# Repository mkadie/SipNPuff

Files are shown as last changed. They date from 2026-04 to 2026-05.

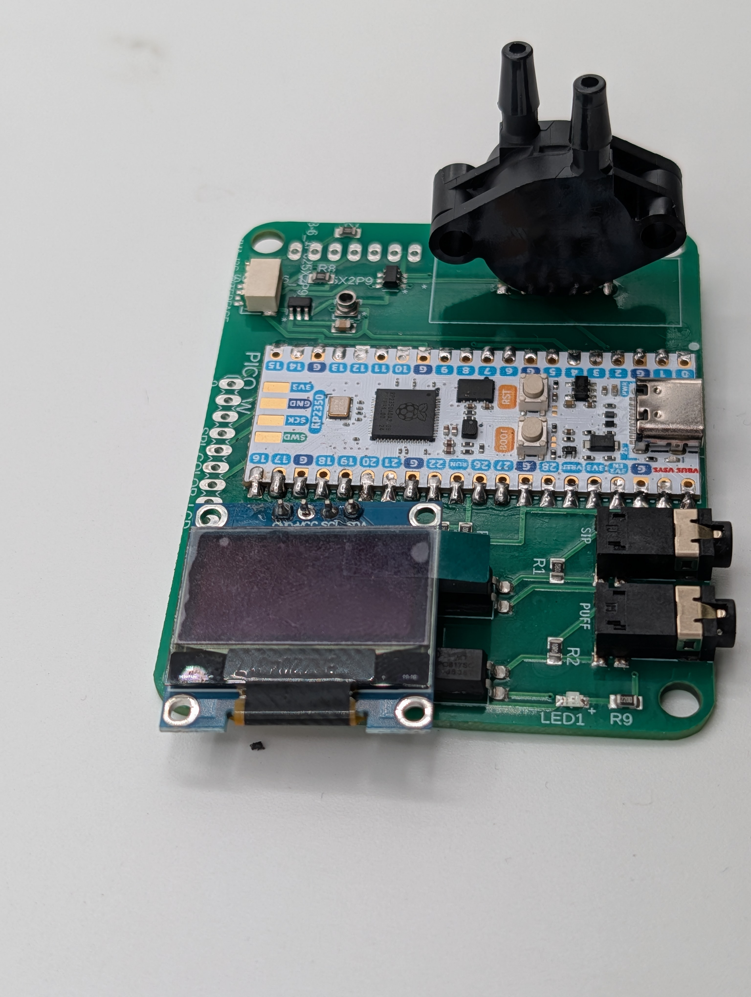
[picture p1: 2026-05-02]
photos/PXL_20260430_184801016.jpg

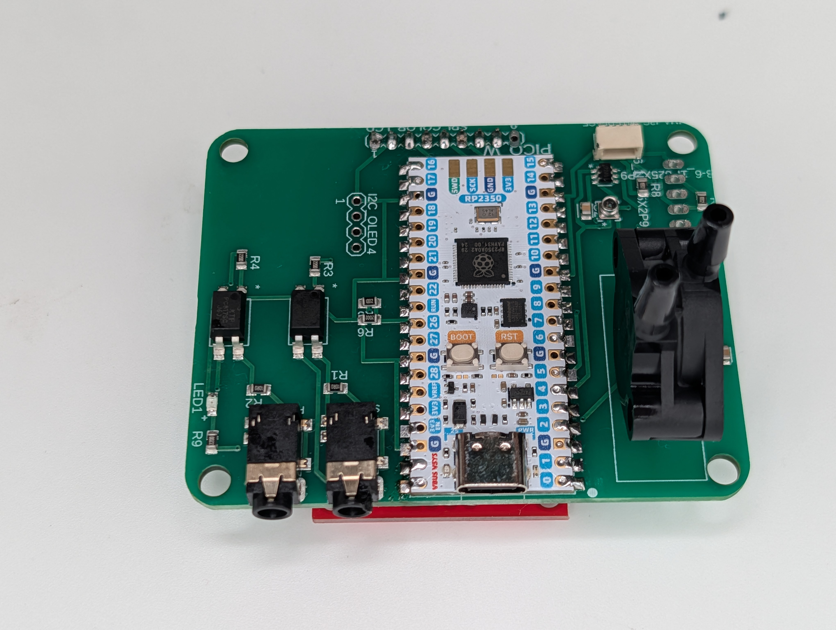
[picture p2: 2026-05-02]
photos/PXL_20260430_184728154.jpg

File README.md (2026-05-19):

# Sip and Puff Rubber Chicken Edition

## Project Overview

This project implements a functional sip and puff switch interface that serves as both a demonstration system (using rubber chickens) and a working, low-cost ($25-50) sip and puff device for accessibility applications. The core functionality focuses on creating a reliable, accessible interface while using the rubber chicken concept as an engaging demonstration tool for normally abled users.

---

## ⭐ Primary Claim to Fame: One Build, Many Purposes — Text File Configuration

> **The defining characteristic of this project is flexibility.**

Most open-source sip and puff devices are purpose-built for a single output: a USB mouse, a keyboard emulator, or a specific AT protocol. Changing what the device *does* means reflashing firmware or editing code. This project takes a different approach: **a single hardware build and a single firmware image that can be reconfigured for completely different tasks by editing a plain text configuration file** — no compiler, no IDE, no programmer required.

A clinician, caregiver, or technically capable user can open the config file (accessible as a USB drive when the device is plugged in) and change:
- What a sip or puff event maps to (keypress, mouse button, joystick axis, HID consumer control, serial command, etc.)
- Sensitivity thresholds for sip and puff, independently
- Operating mode (USB HID mouse, USB HID keyboard, XAC gamepad output, serial AT command relay, etc.)
- Head-tracking parameters (dead zone, speed curve, re-centre trigger gesture)
- Display content and feedback behaviour

The same physical device can serve as:
- A USB mouse (head tracking + sip/puff clicks)
- A two-switch keyboard input (sip = one key, puff = another)
- An Xbox Adaptive Controller input (via the onboard TRRS jacks)
- A demonstration interface (rubber chicken mode for Maker faires)
- A research data collection tool (with optional microSD logging)

No other project in the open-source sip and puff space offers this level of reconfigurability without touching firmware. This is intentional and is the core design goal that drives decisions about display hardware, the EXTERNAL_IO connector, STEMMA QT expansion, and the overall software architecture.

---

## Project Stage

Early, rapid development for prototype by Maker event, which one ... hopefully the next one :)

> **Firmware reference:** see [`FIRMWARE_NOTES.md`](./FIRMWARE_NOTES.md)
> for the current state of the CircuitPython firmware — pressure-sensor
> fusion, event-classifier rules, the on-screen HUD layout, the repeat-rate
> map, IMU pointing, and the full config-key reference. That's the document
> to read before touching `source/breath_classifier.py`,
> `source/sip_puff_device.py`, or any `config.txt` on a deployed device.

## Core Mission

### Primary Focus: Flexibility Through Text File Configuration
The defining goal is a single hardware and software build that can be reconfigured for a wide range of tasks by editing a plain text config file — no reflashing, no coding skills required. The same device adapts to the user, rather than requiring the user to adapt to a fixed device behavior.

### Secondary Focus: Functional Accessibility Interface
The main objective is to develop a robust, affordable sip and puff switch system that can be used for:
- Assistive technology for individuals with motor disabilities
- Accessibility solutions for communication devices
- Research in human-computer interaction
- Educational demonstrations in accessibility technology

### Tertiary Focus: Demonstration and Engagement
The rubber chicken concept serves as an engaging demonstration tool for:
- Maker faires and community events
- Educational outreach programs
- Public demonstrations of accessibility technology
- Engaging users in the concept of assistive interfaces

## Hardware Design

### Primary Components

#### Sensors

> **PCB Strategy:** Initial PCBs support both sensor footprints simultaneously. After real-world testing, separate PCB variants (SMD-only and through-hole) will be produced.

##### Default Sensor: LPS28DFWTR (SMD — I²C digital)
- **Part:** STMicroelectronics LPS28DFWTR
- **Package:** CCLGA-7L, 2.8 × 2.8 × 1.95 mm — SMD only, requires reflow or hot-air soldering
- **Why it's default:** Water-resistant package (potting gel, rated 10 ATM), 24-bit resolution, ultra-low noise (0.32 Pa), factory-calibrated, I²C interface, embedded FIFO, interrupt output, and 1.7 µA idle current
- **Interface:** I²C (up to 400 kHz fast mode; 1 MHz fast mode+) — connects directly to Pico W I²C bus
- **I²C address:** 0x5C (SA0 pin → GND) or 0x5D (SA0 pin → VDD) — selectable via PCB solder bridge
- **Pressure range:** Mode 1: 260–1260 hPa (optimised for sip/puff); Mode 2: 260–4060 hPa
- **Pressure noise:** 0.32 Pa RMS (Mode 1) — more than sufficient for breath detection
- **Accuracy:** ±0.5 hPa absolute, ±0.015 hPa relative
- **ODR:** 1–200 Hz (software configurable)
- **Supply voltage:** 1.7 to 3.6 V (3.3V from Pico W is within spec)
- **Interrupt:** INT_DRDY pin — data-ready interrupt for efficient polling
- **Datasheet:** DS13317 Rev 1, December 2021 (ST Microelectronics)
- **Sensor Placement:** Positioned in breath path between mouthpiece filter and PCB; water-resistant package tolerates condensation exposure

##### Alternative Sensor: MPX5010DP (Through-Hole — Analog output)
- **Part:** NXP/Freescale MPX5010DP
- **Package:** Through-hole SIP-6 — can be hand-soldered without SMD equipment
- **Why it's an alternative:** Easier to hand-solder for early prototypes and events; no SMD tools required
- **Interface:** **Analog voltage output** (0.2V–4.7V at 5V supply) — connects to a Pico ADC pin, **NOT I²C**
- **Pressure range:** 0–10 kPa differential
- **Supply voltage:** 2.7–5.5V (note: at 3.3V supply the output range scales; verify output headroom in firmware)
- **Accuracy:** ±1.5% FS
- **Power consumption:** ~6 mA typical (significantly higher than LPS28DFWTR)
- **Sensor Placement:** Same breath-path position; analog output wire routes to GPIO 26 (ADC0) on Pico W

#### Microcontroller
- **Raspberry Pi RP2040**: Chosen for its cost-effectiveness ($4), dual-core ARM Cortex-M0+ processor, and sufficient processing power for signal conditioning
- **Alternative Options**: 
  - ESP32 for WiFi connectivity
  - Arduino Nano for simpler implementations
  - STM32 for higher performance applications
- **Processing Requirements**: Signal filtering, input classification, and output protocol handling

#### Mechanical Interface
- **Primary Sip/Puff Mechanism**: 
  - Standard straw or tube for suction input
  - Blow tube for pressure input
  - Ergonomic design for comfortable use
- **Alternative Interfaces**: 
  - Custom 3D printed mouthpieces
  - Commercial sip/puff devices
  - Modular interface system for different user needs
- **Enclosure Design**: 
  - Durable, medical-grade materials
  - Easy-to-clean surfaces
  - Ergonomic housing for various user groups
- **Interface Options**: 
  - Standard straw configuration
  - Bellows system for precise suction detection
  - Custom mouthpiece designs

#### Optional Display Connectors

> Both connectors are unpopulated PCB footprints — built-in hardware support with no board redesign needed to add displays later.

##### J1 — I²C OLED Display (1", 128×64)
- **Connector**: 4-pin 2.54 mm Dupont header on PCB
- **Display type**: 1" 128×64 OLED, SSD1306 controller (or compatible)
- **Interface**: I²C — shares existing GPIO 4 (SDA) / GPIO 5 (SCL) bus with the LPS28DFWTR sensor
- **I²C address**: 0x3C (default) or 0x3D — no conflict with LPS28DFWTR at 0x5C/0x5D
- **Supply**: 3.3V
- **Pin order (1→4)**: GND → VCC → SCL → SDA
- **Use case**: Status readout, sip/puff feedback, pressure level bar graph

##### J2 — SPI Color LCD Display (2"–4")
- **Connector**: 9-pin 2.54 mm Dupont header on PCB
- **Display type**: 2"–4" color TFT LCD, ST7789 or ILI9341 controller (or compatible)
- **Interface**: SPI1 hardware peripheral on dedicated non-analog GPIO pins
- **GPIO assignments**:
  - GPIO 10 — SCK (SPI1 clock)
  - GPIO 11 — MOSI / SDI (SPI1 TX)
  - GPIO 12 — MISO / SDO (SPI1 RX, optional)
  - GPIO 13 — CS (chip select, active low)
  - GPIO 14 — DC/RS (high = data, low = command)
  - GPIO 15 — RESET (active low)
  - GPIO 16 — LED (backlight PWM; solder bridge for always-on 3.3V)
- **Pin order (1→9)**: VCC → GND → CS → RESET → DC/RS → MOSI → SCK → LED → MISO
- **Supply**: 3.3V
- **Use case**: Full-color rubber chicken game interface, animated demo display

#### Circuit Protection

> **A commonly overlooked step in open-source hardware projects, including many assistive technology designs.** External-facing I/O lines that connect to the real world — connectors, encoder inputs, expansion ports — are exposed to ESD events and electrical transients. Protecting the microcontroller's GPIO pins from these events is straightforward and inexpensive; skipping it is a common cause of latent damage in both hobby and clinical builds.

- **IC:** SP724AHTG — low-capacitance TVS (transient voltage suppressor) diode array, STMicroelectronics
- **Coverage:** All external-facing I/O lines **not** already protected by opto-isolation:
  - EXTERNAL_IO connector: BUTTON (GPIO 20), ROT_A (GPIO 18), ROT_B (GPIO 19), SDA (GPIO 4), SCL (GPIO 5)
  - STEMMA QT expansion port (SDA, SCL)
  - Display connectors J1 and J2 signal lines as applicable
- **Not needed on:** GPIO 0 (SIP_ENABLE) and GPIO 1 (PUF_ENABLE) — these are already isolated by PC817SC optocouplers before reaching the TRRS jacks
- **Why SP724AHTG:** Low capacitance preserves signal integrity on I²C and SPI lines; small package; single IC can protect multiple lines simultaneously; ~$0.30–0.50 per IC in single-unit quantities

#### Power Supply
- **Battery Option**: PCB designed to accommodate battery but not populated (user-selectable)
- **Optional LDO Power Supply**: For chair-based installations at events
- **Power Management**: 
  - Standalone operation with optional power expansion
  - Low power consumption design for battery operation
  - USB charging capability for convenience
- **Power Requirements**: 
  - Standby: <10mA
  - Active: <50mA
  - Battery life: >20 hours continuous operation

### Cost Analysis

| Component | Cost (single unit) | Notes |
|---|---|---|
| Pressure sensor — LPS28DFWTR | ~$4–6 | **Primary / default.** STMicroelectronics CCLGA-7L SMD; I²C, 24-bit, 0.32 Pa noise, water-resistant potting gel. Requires reflow or hot-air soldering. |
| Microcontroller | ~$4 | Raspberry Pi Pico W (RP2040 + CYW43439) |
| XAC output circuit | ~$2–3 | 2× PC817SC optocouplers + 2× TRRS jacks |
| Circuit protection | ~$1–2 | SP724AHTG TVS array ICs × 2–3 units; protects all I/O lines not covered by opto-isolators |
| Mechanical components | ~$5–10 | Tube, mouthpiece, connectors |
| Enclosure materials | ~$5–10 | 3D-printed or off-the-shelf housing |
| Miscellaneous | ~$5–10 | Resistors, caps, PCB, hardware |
| **Base build total** | **~$21–45** | Functional sip/puff device with XAC output and ESD protection |
| **Optional — MPX5010DP sensor** | **+~$3–5** | Through-hole analog alternative to the LPS28DFWTR; hand-solderable, no SMD tools required. *Depending on performance testing of the LPS28DFWTR vs MPX5010DP, this may remain a supported alternative or be retired from the design.* PCB includes footprint for both — only one is populated. |
| **Optional — BNO055 IMU** | **+~$30–35** | Bosch BNO055 on STEMMA QT breakout (e.g. Adafruit #4646); adds head-tracking (Mode A) and/or tongue-joystick cursor control (Mode B). Post-Maker-Faire upgrade — not required for core sip/puff functionality. Sensor alone costs more than the rest of the BOM combined at single-unit prices. |
| **Optional — display(s)** | **+~$5–15** | J1: 1" SSD1306 OLED ~$3–5; J2: 2–4" color LCD ~$8–15; PCB connectors already present |
| **Optional — hygiene filters** | **~$0.50–2 each** | Recurring consumable; see Section 10.1 of reference doc for filter options |
| **Full build with IMU + display** | **~$56–95** | Still well below comparable commercial AT devices ($175–$325+) |
| **Future / Medical-grade — redundant hardware** | **+~$15–30 est.** | For a medically certified build: a second LPS28DFWTR pressure sensor (cross-checks primary; flags discrepancy as fault condition) plus a second or dedicated safety CPU (hardware watchdog / supervisory MCU to monitor the primary RP2040 and force a safe state on failure). Required for IEC 62304 / FDA Class II pathway. Significant increase in PCB complexity and firmware scope. Not planned for current prototype — noted here as the architectural direction a certified variant would take. The lead designer has prior involvement in the design and manufacture of an FDA-regulated medical device (a lithium battery system for power wheelchairs, developed in conjunction with an established powerchair manufacturer), making this a realistic rather than purely aspirational future direction. See Section 10.7 of the reference doc for full detail. |

- **Manufacturing Considerations**: 
  - Scalable production design
  - Component sourcing for cost optimization
  - Quality control procedures

## Software Architecture

### Core Functionality

The system operates as a reliable, functional sip and puff interface with the following core features:

1. **Pressure Sensing**: Continuous monitoring of pressure sensor data with filtering — I²C polling (LPS28DFWTR default) or ADC sampling (MPX5010DP alternative)
2. **Input Classification**: Distinguishing between sip and puff actions with threshold detection
3. **Signal Processing**: Debouncing and smoothing of pressure readings
4. **Command Generation**: Converting pressure inputs into actionable commands
5. **Output Protocol**: Providing standardized outputs for various applications

### Input/Output Processing

#### Input Detection
- **Suction Detection**: Threshold detection for negative pressure (sip)
- **Blow Detection**: Threshold detection for positive pressure (puff)
- **Hold Detection**: Continuous pressure monitoring for extended commands
- **Debouncing**: Filtering for false triggers and noise reduction

#### Output Protocols
- **Digital Outputs**: 
  - Binary signals for on/off commands
  - Multi-level outputs for different command types
  - Serial communication for complex data transfer
- **Analog Outputs**: 
  - Voltage level representation of pressure
  - Proportional response for advanced applications
- **Communication Protocols**: 
  - I2C for LPS28DFWTR sensor communication (default); ADC for MPX5010DP (alternative)
  - UART for serial data transfer
  - USB for PC connectivity

### Command Structure
- **Basic Commands**: 
  - Sip (negative pressure)
  - Puff (positive pressure)
  - Hold (extended pressure)
- **Advanced Commands**: 
  - Double tap
  - Long press
  - Pattern recognition
- **Customizable Mapping**: 
  - User-defined command associations
  - Application-specific command sets

## Technical Specifications

### Electrical Specifications
- **Supply Voltage**: 3.3V or 5V (user selectable)
- **Current Consumption**: <50mA (standby), <100mA (active)
- **Operating Temperature**: -20°C to +70°C
- **Humidity Range**: 5% to 95% RH (non-condensing)
- **Input Impedance**: High impedance for sensor compatibility
- **Output Impedance**: Low impedance for reliable signal transmission

### Mechanical Specifications
- **Dimensions**: 150mm × 100mm × 50mm (approximate)
- **Weight**: <200g (excluding power source)
- **Input Force Range**: -500Pa to +500Pa
- **Response Time**: <100ms for pressure changes
- **Interface Materials**: Medical-grade, non-toxic materials
- **Durability**: >100,000 cycles of operation

### Performance Metrics
- **Accuracy**: ±2% for pressure measurements
- **Repeatability**: ±1% across multiple readings
- **Detection Threshold**: 50Pa for both suction and blowing
- **Operating Life**: >100,000 cycles
- **Reliability**: 99.5% uptime under normal conditions
- **Noise Resistance**: >60dB signal-to-noise ratio

## Accessibility Applications

### User Groups
- **Motor Disabled Individuals**: 
  - Spinal cord injury patients
  - Cerebral palsy users
  - ALS patients
  - Stroke recovery patients
- **Communication Needs**: 
  - Augmentative and alternative communication (AAC)
  - Voice output communication aids
  - Environmental control systems
- **Research Applications**: 
  - Motor function assessment
  - Rehabilitation technology
  - User interface studies

### Integration Capabilities
- **Communication Devices**: 
  - Text-to-speech systems
  - Voice synthesis units
  - Communication boards
- **Environmental Control**: 
  - Home automation systems
  - Lighting controls
  - Temperature regulation
- **Assistive Technology**: 
  - Wheelchair controls
  - Computer interface systems
  - Mobile device control

## Demonstration System (Rubber Chicken Concept)

### Purpose
- **Engagement Tool**: Make accessibility technology approachable and fun
- **Educational Aid**: Demonstrate principles of sip and puff technology
- **Community Outreach**: Attract attention to accessibility needs
- **Public Awareness**: Showcase assistive technology capabilities

### Demonstration Features
- **Rubber Chicken Interface**: 
  - Visual representation of the technology
  - Engaging user experience
  - Easy to understand concept
- **Interactive Gameplay**: 
  - Educational quiz system
  - Game-based learning
  - User engagement metrics
- **Public Display**: 
  - Maker faire setup
  - Educational booth
  - Community demonstration

### Technical Integration
- **Dual Functionality**: 
  - Real sip/puff system for actual use
  - Demonstration system for public engagement
- **Switching Mechanism**: 
  - User-selectable modes
  - Automatic mode detection
  - Context-aware operation

## Open Source Philosophy

### Documentation
- **Hardware**: Complete schematics, PCB layouts, BOM
- **Software**: Full source code with detailed comments
- **Assembly**: Step-by-step instructions
- **Calibration**: Testing and validation procedures
- **Applications**: Usage examples and integration guides

### Community Engagement
- **GitHub Repository**: Collaborative development environment
- **Issue Tracking**: Feature requests and bug reporting
- **Contribution Guidelines**: Clear development standards
- **Version Control**: Stable releases and development branches
- **Integration Tools**: Compatibility with maker ecosystem

## Research and Development Applications

### Academic Potential
- **Human-Computer Interaction**: 
  - Accessible interface design
  - User experience studies
  - Motor disability research
- **Assistive Technology**: 
  - Device development
  - User testing protocols
  - Technology evaluation
- **Engineering Education**: 
  - Hands-on learning projects
  - Design methodology
  - Prototyping techniques

### Publication Goals
- **IEEE Venues**: 
  - Accessibility technology papers
  - Human-computer interaction research
  - Assistive device development
- **Conference Presentations**: 
  - Maker faire demonstrations
  - Educational outreach
  - Research findings
- **Academic Papers**: 
  - Technical specifications
  - Performance analysis
  - User study results

## Scalability and Future Development

### Modular Design
- **Interface Expansion**: 
  - Different mechanical configurations
  - Customizable user interfaces
  - Modular component system
- **Protocol Support**: 
  - Multiple output standards
  - Integration with existing systems
  - Future-proof architecture
- **Upgrade Path**: 
  - Hardware improvements
  - Software enhancements
  - Feature additions

### Market Applications
- **Educational Institutions**: 
  - STEM learning tools
  - Engineering design projects
  - Accessibility education
- **Healthcare Providers**: 
  - Assistive technology solutions
  - Rehabilitation equipment
  - Clinical research tools
- **Research Labs**: 
  - Human-computer interaction studies
  - Device development
  - User interface research

## Conclusion

The Sip and Puff Rubber Chicken Edition represents a dual-purpose system that successfully balances accessibility functionality with community engagement. While the core focus remains on creating a reliable, affordable sip and puff interface for individuals with motor disabilities, the rubber chicken demonstration serves as an effective tool for public education and community outreach.

This approach ensures that the technology serves its primary purpose of supporting accessibility needs while also generating interest and understanding in the broader community. The system's modular design, open source nature, and focus on affordability position it well for both immediate practical applications and long-term research and development opportunities.

The project demonstrates how maker culture can contribute meaningfully to accessibility technology, creating solutions that are not only functional but also engaging and educational. By maintaining focus on the core sip and puff functionality while using the rubber chicken concept for demonstration, this system successfully bridges the gap between serious assistive technology and community engagement.

## Future

Taking inspiration from other sip and puff open source projects we will attempt to integrate mouse functionality after Maker Faire as time and schedule permit. The mouse feature is a software extension and should be comparatively easy.

### Head-Tracking via IMU (Phase 2 — Post-Maker-Faire)

The longer-term plan is to add **head-movement-based cursor control** using an IMU sensor, combining it with sip/puff for mouse clicks. This approach was validated in a peer-reviewed 2025 study ([S1] in the Reference doc) and is well-suited to users with high-level spinal cord injury or other conditions where oral motor control is limited.

**Selected sensor: Bosch BNO055** (~$30–35 on a STEMMA QT breakout)

The BNO055 was chosen over cheaper 6-DOF alternatives (MPU-6050, BMI270, LSM6DSOX) because it includes an on-board sensor fusion processor that outputs clean Euler angles and quaternions directly — no Kalman or Madgwick filter to implement. Its built-in magnetometer (9 DOF) also eliminates the yaw drift problem that affects 6-axis-only sensors during prolonged use, which is a real usability burden for a head mouse used over hours. The cost premium (~$25 over a basic IMU) is justified in context — it is a one-time addition, comparable in scale to a few rounds of replacement hygiene filters.

**Two mounting modes — same hardware, different placement:**

**Mode A — Head Strap / Glasses Mount:** The BNO055 is clipped to a glasses frame, forehead strap, or ear clip. Head nods and tilts move the cursor. Best for users with good head mobility. I²C wires run from the STEMMA QT port along the tube to the sensor on the head.

**Mode B — Tongue Joystick via Straw Attachment:** A small 3D-printed collar clips the BNO055 to the sip/puff tube near the mouthpiece. The user deflects the straw with their tongue — left, right, up, down — and the BNO055 detects the angular change of the tube. The straw becomes the joystick lever. Best for users with good tongue or lip control but limited head movement. Same hardware as Mode A, just repositioned.

With proper configuration the required activation force can be significantly reduced. The collar's position along the tube acts as a lever — moving it further from the tip lengthens the lever arm so a lighter tongue push produces a larger angular signal. Tube material flexibility also plays a role. On the software side, the sensitivity and dead zone settings in the config file can be tuned so that very small movements register as valid input without making the cursor jittery at rest. This makes Mode B viable for users with very limited tongue or lip strength, and gives clinicians a way to adjust force requirements without any hardware changes.

Switching between modes is a config file change (sensitivity, dead zone, and axis orientation parameters) — no reflashing required. This is a direct expression of the project's core flexibility goal.

**Hardware readiness:** No PCB changes are needed. The STEMMA QT expansion port (GPIO 4/5 I²C bus) is already present on the board for exactly this purpose. The BNO055's I²C address (0x28 or 0x29) does not conflict with any other device on the shared bus.

A three-way hybrid — head tracking, tongue joystick, and Hall-effect mouthpiece stick as selectable modes on the same hardware — is a longer-term stretch goal. No existing reviewed open-source project offers even two of these three options.

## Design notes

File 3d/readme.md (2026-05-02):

# 3D Models

Mechanical models for the T-Rex Sip-N-Puff HID enclosure and assembly.

## Contents

| File | Format | Description |
|---|---|---|
| `SipNPuff.step` | STEP (AP214) | First article prototype assembly — full 3D model of the electronics and enclosure concept |

## Importing the STEP File

The STEP file can be opened in any major CAD package:

- **Fusion 360** — File → Open → select `.step`
- **FreeCAD** — File → Import → select `.step`
- **SolidWorks** — File → Open → select `.step`
- **KiCad 3D Viewer** — for PCB enclosure fit checks

If you downloaded the compressed `.step.gz` version, decompress it first:

```bash
gunzip SipNPuff.step.gz
```

## Notes

- This model represents the first article prototype. Enclosure design will evolve as the project moves from breadboard to production form factor.
- See the `photos/` directory for build photos of this prototype.
- Electronics BOM, schematic, and firmware are in the project root.

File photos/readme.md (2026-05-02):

# Prototype Photos

First article prototype of the T-Rex Sip-N-Puff HID electronics assembly.

These photos document the initial build of the Raspberry Pi Pico-based sip and puff human interface device, including the MPX5010DP pressure sensor, PC817 optocoupler outputs for the Xbox Adaptive Controller, and optional I2C display modules.

## Contents

| File | Description |
|---|---|
| PCB front view | Top side of the assembled board showing the Pico, pressure sensor, and supporting components |
| PCB back/rotated | Reverse angle showing board layout |
| PCB with TFT display | Assembly with TFT display module attached via I2C |
| PCB with OLED and tubing | Assembly with OLED display and sip/puff tubing connected to the MPX5010DP |
| PCB underside | Solder joint quality on the bottom of the board |
| Full assembly | Complete build with sip tube mounted to the board |

## Notes

- This is a first article prototype — form factor and layout are subject to change as the enclosure design matures.
- See the `3d/` directory for the initial mechanical model.
- See the project root for full BOM, schematic, and firmware.

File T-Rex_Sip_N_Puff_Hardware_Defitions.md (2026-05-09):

Got it—less talk, more traces. Since you're using the **Raspberry Pi Pico** layout and want to keep your **SPI interfaces** wide open while maintaining a specific pin order for the encoder, we’ll move the logic to the "bottom" end of the Pico’s GPIO bank.

This configuration uses **GP26** (the lowest ADC) for the chicken-bellows sensor and groups your encoder outputs together starting at **GP18**, leaving **GP0–GP7 (SPI0)** and **GP8–GP11 (SPI1)** completely untouched for your other hardware needs.

### 1. Hardware Mapping & Schematic Logic

| Pico Pin | Label | Function | Connection Note |
| :--- | :--- | :--- | :--- |
| **VBUS (Pin 40)** | 5V_RAIL | Power for MPX5010DP | [cite_start]Use the 5V USB line to power the sensor[cite: 9]. |
| **GND (Pin 38)** | GND | Common Ground | [cite_start]Tie all sensor, opto, and Pico grounds here[cite: 22]. |
| **GP26 (Pin 31)** | ADC0 | Pressure Input | [cite_start]Lowest ADC; requires a voltage divider (see below)[cite: 15, 16]. |
| **GP16 (Pin 21)** | XAC_PULSE | Opto 1 Control | [cite_start]Drives the "Puff" signal to the Xbox Controller[cite: 13, 21]. |
| **GP17 (Pin 22)** | XAC_SELECT | Opto 2 Control | [cite_start]Drives the "Double Puff" signal to the XAC[cite: 13, 21]. |
| **GP18 (Pin 24)** | ENC_A | Encoder Phase A | First part of the consecutive encoder block. |
| **GP19 (Pin 25)** | ENC_B | Encoder Phase B | Middle of the consecutive encoder block. |
| **GP20 (Pin 26)** | ENC_BTN | Encoder Button | End of the consecutive block; no "middle" button. |

---

### 2. Critical Wiring Sub-Circuits

#### **The Voltage Divider (Pressure Sensor)**
[cite_start]The MPX5010DP outputs up to **4.7V**, which will fry your Pico's ADC if connected directly[cite: 14, 15].
* [cite_start]**Sensor Output Pin** $\rightarrow$ $10k\Omega$ Resistor $\rightarrow$ **Pico GP26 (ADC0)**[cite: 12, 16].
* [cite_start]**Pico GP26 (ADC0)** $\rightarrow$ $20k\Omega$ Resistor $\rightarrow$ **GND**[cite: 12, 16].
* [cite_start]*Result:* This scales 5V down to ~3.33V, safe for the RP2040[cite: 16].

#### **The XAC Optocouplers (Dry Contact)**
Repeat this for both GP16 and GP17 to provide isolated signals to the Xbox Adaptive Controller:
1.  [cite_start]**Pico GPIO** $\rightarrow$ $220\Omega$ Resistor $\rightarrow$ **PC817 Pin 1 (Anode)**[cite: 12, 21].
2.  [cite_start]**PC817 Pin 2 (Cathode)** $\rightarrow$ **GND**[cite: 22].
3.  [cite_start]**PC817 Pin 3 (Emitter)** $\rightarrow$ **3.5mm Jack Sleeve**[cite: 22].
4.  [cite_start]**PC817 Pin 4 (Collector)** $\rightarrow$ **3.5mm Jack Tip**[cite: 13, 22].

---

### 3. CircuitPython Pin Definitions
When you start coding your "Chicken Challenge" logic, initialize your pins like this to match the schematic above:

```python
import board
import analogio
import digitalio

# Pressure Sensor on the lowest ADC
pressure_sensor = analogio.AnalogIn(board.GP26)

# Encoder Emulation (Consecutive Pins, Button at end)
enc_a = digitalio.DigitalInOut(board.GP18)
enc_b = digitalio.DigitalInOut(board.GP19)
enc_btn = digitalio.DigitalInOut(board.GP20)

# XAC Isolated Outputs
xac_puff = digitalio.DigitalInOut(board.GP16)
xac_select = digitalio.DigitalInOut(board.GP17)
```

### 4. Implementation Tips for Fusion Electronics
* **SPI Availability:** By starting your encoder block at **GP18**, you've kept the primary SPI0 (GP0-3) and SPI1 (GP8-11) blocks completely clear of any signal overlap.
* **Net Naming:** In Eagle/Fusion, name your nets **5V_SENSOR** and **3V3_PICO** clearly. The MPX5010DP is picky about power stability; if your rubber chicken "puffs" cause voltage dips, add a $0.1\mu F$ decoupling capacitor between the sensor's Vcc and GND pins.

Since you're using CircuitPython, would you like a snippet for the **non-blocking timer logic** that handles the "Puff vs. Double Puff" detection without stopping your main game loop?

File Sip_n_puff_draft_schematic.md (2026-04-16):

# Sip and Puff Rubber Chicken Edition - Schematics

> **Dual Sensor PCB Strategy:** Initial PCBs include footprints for both the LPS28DFWTR (SMD, I²C — default) and the MPX5010DP (through-hole, analog — alternative). Only one sensor is populated at a time. After real-world testing, separate PCB variants will be spun. Sections below document both wiring options clearly.

## Hardware Schematic Overview

```
                    SIP AND PUFF RUBBER CHICKEN EDITION — TOP-LEVEL OVERVIEW

          DEFAULT SENSOR                      ALTERNATIVE SENSOR
    ┌──────────────────────┐           ┌──────────────────────┐
    │   LPS28DFWTR (SMD)   │           │  MPX5010DP (TH)      │
    │   I²C digital        │           │  Analog output        │
    │   GPIO 4 (SDA)       │           │  GPIO 26 (ADC0)       │
    │   GPIO 5 (SCL)       │           │  (one or the other    │
    │   GPIO 6 (INT, opt.) │           │   is populated)       │
    └──────────┬───────────┘           └──────────┬────────────┘
               │  I²C / ADC                        │
               └──────────────┬────────────────────┘
                              │
                    ┌─────────▼──────────┐
                    │                    │
                    │   Pico W / RP2040  │
                    │   Microcontroller  │
                    │                    │
                    │  GPIO 0 → SIP_ENABLE (OUT) │  → PC817 opto → TRRS jack
                    │  GPIO 1 → PUF_ENABLE (OUT) │  → PC817 opto → TRRS jack
                    │  GPIO 2 → Status LED       │
                    │  GPIO 4 → I²C SDA          │  (LPS28DFWTR default)
                    │  GPIO 5 → I²C SCL          │  (LPS28DFWTR default)
                    │  GPIO 6 → INT_DRDY         │  (LPS28DFWTR optional)
                    │  GPIO 26 → ADC0            │  (MPX5010DP alternative)
                    │                    │
                    └─────────┬──────────┘
                              │
          ┌───────────────────┼──────────────┐
          │                   │              │
    ┌─────▼──────────┐  ┌─────▼───────────┐  ┌───▼────────────┐
    │ SIP_ENABLE out │  │ PUF_ENABLE out  │  │  Status LED    │
    │ → PC817 opto   │  │ → PC817 opto    │  │  GPIO 2        │
    │ → TRRS 3.5mm   │  │ → TRRS 3.5mm   │  └────────────────┘
    │   (XAC output) │  │   (XAC output)  │
    └────────────────┘  └─────────────────┘

    ⚠ NOTE: Sip/puff is DETECTED by the pressure sensor (LPS28DFWTR
    via I²C or MPX5010DP via ADC). GPIO 0/1 are OUTPUTS — they
    signal a detected sip/puff event to an external XAC or AT
    device via PC817 optocoupler-isolated TRRS 3.5mm jacks.
```

## DEFAULT Sensor Schematic — LPS28DFWTR (SMD, I²C)

```
    LPS28DFWTR — CCLGA-7L PINOUT (bottom view)
    ┌──────────────────────────────────────────────────┐
    │  Pin 1  SDA      → Pico W GPIO 4  (I2C0 SDA)    │
    │  Pin 2  SA0      → GND           (addr = 0x5C)  │
    │                    or VDD        (addr = 0x5D)  │
    │  Pin 3  SCL      → Pico W GPIO 5  (I2C0 SCL)    │
    │  Pin 4  INT_DRDY → Pico W GPIO 6  (optional IRQ) │
    │  Pin 5  GND      → GND                          │
    │  Pin 6  VDD      → 3.3V                         │
    │  Pin 7  PAD2LID  → GND  (or float)              │
    └──────────────────────────────────────────────────┘

    I²C PULL-UP RESISTORS (required):
    ┌────────────────────────────────────────────────────┐
    │  SDA (GPIO 4) ──┬── 10kΩ ── 3.3V                 │
    │  SCL (GPIO 5) ──┴── 10kΩ ── 3.3V                 │
    │                                                    │
    │  Note: Pico W internal pull-ups are weak (~50kΩ); │
    │  external 10kΩ resistors are required for        │
    │  reliable I²C at 400 kHz.                         │
    └────────────────────────────────────────────────────┘

    DECOUPLING CAPACITOR (required):
    ┌────────────────────────────────────────────────────┐
    │  100nF ceramic cap between VDD (pin 6) and GND    │
    │  placed as close to the sensor as possible        │
    └────────────────────────────────────────────────────┘

                    LPS28DFWTR I²C CONNECTION
                    ┌─────────────────────────────┐
                    │                             │
                    │   LPS28DFWTR (CCLGA-7L SMD) │
                    │   ┌─────────────────────┐   │
                    │   │                     │   │
                    │   │  VDD  ────── 3.3V   │   │
                    │   │  GND  ────── GND    │   │
                    │   │  SDA  ────── GPIO 4 │   │
                    │   │  SCL  ────── GPIO 5 │   │
                    │   │  SA0  ────── GND    │   │  (I²C addr 0x5C)
                    │   │  INT_DRDY ── GPIO 6 │   │  (optional)
                    │   │  PAD2LID ── GND     │   │
                    │   │                     │   │
                    │   └─────────────────────┘   │
                    │                             │
                    │   I²C Pull-ups:             │
                    │   GPIO 4 ──10kΩ── 3.3V    │
                    │   GPIO 5 ──10kΩ── 3.3V    │
                    │   Decoupling: 100nF VDD–GND │
                    │                             │
                    └─────────────────────────────┘

    KEY SPECS (from DS13317 Rev 1):
    • Pressure range:  260–1260 hPa (Mode 1) / 260–4060 hPa (Mode 2)
    • Noise:           0.32 Pa RMS (Mode 1 @ 25°C)
    • Resolution:      24-bit
    • ODR:             1–200 Hz (software selectable)
    • Supply:          1.7–3.6 V  →  3.3V nominal
    • Current:         1.7 µA typical (AVG=4, ODR=1 Hz)
    • Water-resistant: potting gel, rated 10 ATM
    • Factory calibrated — no user calibration required
    • I²C addresses:   0x5C (SA0=GND) or 0x5D (SA0=VDD)
```

## ALTERNATIVE Sensor Schematic — MPX5010DP (Through-Hole, Analog)

> **Note:** The MPX5010DP outputs an **analog voltage** (not I²C). It must connect to a Pico ADC pin (GPIO 26/27/28), not to the SDA/SCL I²C bus. Earlier documentation incorrectly described this as "Digital I²C" — that was an error and has been corrected.

```
    MPX5010DP CONNECTIONS (when populated instead of LPS28DFWTR):
    ┌──────────────────────────────────────────────────────┐
    │  Pin 1  (V+)   → 5V   (VBUS)                        │
    │  Pin 2  (V-)   → GND                                │
    │  Pin 3  (Vout) → R5 (10kΩ) → Pico W GPIO 26 (ADC0) │
    │  Pin 4  (not connected or GND per datasheet)        │
    │  Pin 5  (Vs)   → 5V   (VBUS)                        │
    │  Pin 6  (GND)  → GND                                │
    └──────────────────────────────────────────────────────┘

    ⚠ VOLTAGE DIVIDER REQUIRED: MPX5010DP is supplied from 5V.
    At 5V supply, Vout range is 0.2V–4.7V — exceeds the Pico W
    ADC maximum of 3.3V. R5 (10kΩ) is the top leg of a voltage
    divider on the Vout line to protect GPIO 26 (ADC0).
    A pull-down resistor to GND completes the divider to bring
    the maximum ADC input voltage to ≤ 3.3V.
    Divider target: Vout_max (4.7V) × R_bottom / (10k + R_bottom) ≤ 3.3V
    → R_bottom ≈ 20kΩ gives 4.7V × 20/30 = 3.13V ✓

    DECOUPLING:
    ┌────────────────────────────────────────────────────┐
    │  100nF + 10µF caps on supply pins                 │
    └────────────────────────────────────────────────────┘

                    MPX5010DP ANALOG CONNECTION
                    ┌─────────────────────────────┐
                    │                             │
                    │   MPX5010DP (Through-Hole)  │
                    │   ┌─────────────────────┐   │
                    │   │                     │   │
                    │   │  V+   ────── 5V (VBUS)          │   │
                    │   │  V-   ────── GND               │   │
                    │   │  Vout ── R5 (10kΩ) ── GPIO 26  │   │  (ADC0 — via divider)
                    │   │  Vs   ────── 5V (VBUS)          │   │
                    │   │  GND  ────── GND               │   │
                    │   │                     │   │
                    │   └─────────────────────┘   │
                    │                             │
                    │   Decoupling:               │
                    │   100nF + 10µF on V+ / GND  │
                    │   (NO I²C pull-ups needed)  │
                    │                             │
                    └─────────────────────────────┘

    KEY SPECS:
    • Pressure range:  0–10 kPa differential
    • Output:          Analog voltage (0.2V–4.7V @ 5V supply)
    • Accuracy:        ±1.5% FS
    • Supply:          5V (VBUS) — do not use 3.3V (degrades output range)
    • Package:         Through-hole SIP — hand-solderable
    • Interface:       ADC (not I²C)
    • ADC protection:  R5 (10kΩ) + ~20kΩ to GND voltage divider on Vout
                       → scales 4.7V max to ~3.1V safe for Pico W ADC
```

## Detailed Circuit Schematic

```
                           SIP AND PUFF SYSTEM
                          ┌─────────────────────────────┐
                          │                             │
                          │  PRESSURE SENSOR (choose 1) │
                          │                             │
                          │  DEFAULT: LPS28DFWTR (SMD)  │
                          │   VDD  ────── 3.3V          │
                          │   GND  ────── GND           │
                          │   SDA  ────── GPIO 4        │
                          │   SCL  ────── GPIO 5        │
                          │   SA0  ────── GND (0x5C)    │
                          │   INT_DRDY ── GPIO 6 (opt.) │
                          │                             │
                          │  ALT: MPX5010DP (TH analog) │
                          │   V+   ────── 5V (VBUS)     │
                          │   Vout ── R5 10kΩ ── GPIO 26│  (ADC, via divider)
                          │   GND  ────── GND           │
                          │                             │
                          └─────────────────────────────┘
                                    │
                                    │
                            ┌───────▼───────┐
                            │               │
                            │   RP2040      │
                            │   Microcontroller│
                            │               │
                            │   GPIO 0 ────┬─┤
                            │   GPIO 1 ────┬─┤
                            │   GPIO 2 ────┬─┤
                            │   GPIO 3 ────┬─┤
                            │   GPIO 4 ────┬─┤
                            │   GPIO 5 ────┬─┤
                            │   GPIO 6 ────┬─┤
                            │   GPIO 7 ────┬─┤
                            │   GPIO 8 ────┬─┤
                            │   GPIO 9 ────┬─┤
                            │   GPIO 10 ───┬─┤
                            │   GPIO 11 ───┬─┤
                            │   GPIO 12 ───┬─┤
                            │   GPIO 13 ───┬─┤
                            │   GPIO 14 ───┬─┤
                            │   GPIO 15 ───┬─┤
                            │   GPIO 16 ───┬─┤
                            │   GPIO 17 ───┬─┤
                            │   GPIO 18 ───┬─┤
                            │   GPIO 19 ───┬─┤
                            │   GPIO 20 ───┬─┤
                            │   GPIO 21 ───┬─┤
                            │   GPIO 22 ───┬─┤
                            │   GPIO 23 ───┬─┤
                            │   GPIO 24 ───┬─┤
                            │   GPIO 25 ───┬─┤
                            │   GPIO 26 ───┬─┤
                            │   GPIO 27 ───┬─┤
                            │   GPIO 28 ───┬─┤
                            │   GPIO 29 ───┬─┤
                            │   GPIO 30 ───┬─┤
                            │   GPIO 31 ───┬─┤
                            │               │
                            │   VBUS ──────┬─┤
                            │   VSYS ──────┬─┤
                            │   GND ───────┬─┤
                            │   VREGIN ────┬─┤
                            │               │
                            └───────────────┘
                                    │
                                    │
                            ┌───────▼───────┐
                            │               │
                            │   Power Supply│
                            │   (3.3V Reg)  │
                            │               │
                            │   VIN ────────┤
                            │   VOUT ───────┤
                            │   GND ────────┤
                            │               │
                            └───────────────┘
                                    │
                                    │
                            ┌───────▼───────┐
                            │               │
                            │   Rubber      │
                            │   Chicken     │
                            │   Sip         │
                            │   Interface   │
                            │   (Demonstr.) │
                            │               │
                            └───────────────┘
                                    │
                                    │
                            ┌───────▼───────┐
                            │               │
                            │   Rubber      │
                            │   Chicken     │
                            │   Puff        │
                            │   Interface   │
                            │   (Demonstr.) │
                            │               │
                            └───────────────┘
                                    │
                                    │
                            ┌───────▼───────┐
                            │               │
                            │   Rubber      │
                            │   Chicken     │
                            │   Status      │
                            │   Indicator   │
                            │   (Demonstr.) │
                            │               │
                            └───────────────┘
```

## Power Supply Circuit

```
                    POWER SUPPLY CIRCUIT
                    ┌─────────────────────────────┐
                    │                             │
                    │   VIN (5V)                  │
                    │   ┌─────────────────────┐   │
                    │   │                     │   │
                    │   │  3.3V REGULATOR     │   │
                    │   │  (LDO)              │   │
                    │   │                     │   │
                    │   │  VOUT ────┬─── 3.3V  │   │
                    │   │  GND ─────┴─── GND   │   │
                    │   │                     │   │
                    │   └─────────────────────┘   │
                    │                             │
                    │   VBUS ────┬─── 5V          │
                    │   VSYS ────┴─── 5V          │
                    │                             │
                    └─────────────────────────────┘
```

## Signal Processing Circuit

```
                    SIGNAL PROCESSING CIRCUIT
                    ┌──────────────────────────────────────┐
                    │                                      │
                    │  DEFAULT: LPS28DFWTR (I²C digital)  │
                    │   ┌──────────────────────────────┐   │
                    │   │  VDD ────────── 3.3V         │   │
                    │   │  GND ────────── GND          │   │
                    │   │  SDA ────────── GPIO 4       │   │
                    │   │  SCL ────────── GPIO 5       │   │
                    │   │  SA0 ────────── GND (0x5C)   │   │
                    │   │  INT_DRDY ────── GPIO 6 (opt)│   │
                    │   │  PAD2LID ─────── GND         │   │
                    │   └──────────────────────────────┘   │
                    │                                      │
                    │  I²C Pull-up Resistors (required):   │
                    │   GPIO 4 (SDA) ──10kΩ── 3.3V       │
                    │   GPIO 5 (SCL) ──10kΩ── 3.3V       │
                    │  Decoupling: 100nF on VDD–GND        │
                    │                                      │
                    │  ALTERNATIVE: MPX5010DP (analog ADC) │
                    │   ┌──────────────────────────────┐   │
                    │   │  V+   ────────── 5V (VBUS)   │   │
                    │   │  GND  ────────── GND         │   │
                    │   │  Vout ── R5 10kΩ ── GPIO 26  │   │  (divider req.)
                    │   │
                    │   │                  (ADC0)      │   │
                    │   └──────────────────────────────┘   │
                    │  Decoupling: 100nF + 10µF on V+–GND  │
                    │                                      │
                    └──────────────────────────────────────┘
```

## XAC / AT Output Circuit (GPIO 0 & 1)

> **Important:** GPIO 0 and GPIO 1 are **outputs**, not inputs. Sip/puff is detected by
> the pressure sensor. These GPIOs signal a detected event to an external XAC (Xbox
> Adaptive Controller) or AT device via PC817 optocouplers and TRRS 3.5mm jacks.

```
                    XAC OUTPUT CIRCUIT — SIP_ENABLE (GPIO 0) & PUF_ENABLE (GPIO 1)
                    ┌──────────────────────────────────────────────────┐
                    │                                                  │
                    │   SIP_ENABLE (GPIO 0)                            │
                    │   ┌───────────────────────────────────────────┐  │
                    │   │                                           │  │
                    │   │  GPIO 0 ─── R (current limit) ──┐        │  │
                    │   │                                  ▼        │  │
                    │   │                    PC817SC OPTO  │        │  │
                    │   │                    ┌──────────┐  │        │  │
                    │   │                    │ LED anode│◄─┘        │  │
                    │   │                    │ LED cath ├── GND     │  │
                    │   │                    │          │           │  │
                    │   │                    │ Collector├── SIP_TIP1│  │  → TRRS TIP
                    │   │                    │ Emitter  ├── GND_SIP │  │  → TRRS GND
                    │   │                    └──────────┘           │  │
                    │   │                                           │  │
                    │   └───────────────────────────────────────────┘  │
                    │                                                  │
                    │   PUF_ENABLE (GPIO 1) — identical circuit        │
                    │   → separate PC817SC → separate TRRS 3.5mm jack  │
                    │                                                  │
                    │   TRRS JACK PINOUT (TRRS_2SWITCH_PJ332A):        │
                    │     TIP   = switch signal (from opto collector)  │
                    │     RING1 = MICDET                               │
                    │     RING2 = switch signal                        │
                    │     SLEEVE = GND                                 │
                    │                                                  │
                    └──────────────────────────────────────────────────┘
```

## Status LED Circuit

```
                    STATUS LED CIRCUIT
                    ┌─────────────────────────────┐
                    │                             │
                    │   STATUS LED                │
                    │   ┌─────────────────────┐   │
                    │   │                     │   │
                    │   │  GPIO 2 ────┬─── 220Ω │   │
                    │   │  VCC ───────┴─── 3.3V │   │
                    │   │  GND ───────┴─── GND   │   │
                    │   │                     │   │
                    │   └─────────────────────┘   │
                    │                             │
                    │   LED COLOR: GREEN          │
                    │   (Optional: RED or BLUE)   │
                    │                             │
                    └─────────────────────────────┘
```

## Complete System Schematic

```
                    COMPLETE SYSTEM SCHEMATIC
                    ┌─────────────────────────────────────────────────────────────┐
                    │                                                             │
                    │                    POWER SUPPLY                             │
                    │                    ┌─────────────────────────────┐          │
                    │                    │                             │          │
                    │                    │   VIN (5V)                    │          │
                    │                    │   ┌─────────────────────┐     │          │
                    │                    │   │                     │     │          │
                    │                    │   │  3.3V REGULATOR     │     │          │
                    │                    │   │  (LDO)              │     │          │
                    │                    │   │                     │     │          │
                    │                    │   │  VOUT ────┬─── 3.3V   │     │          │
                    │                    │   │  GND ─────┴─── GND     │     │          │
                    │                    │   │                     │     │          │
                    │                    │   └─────────────────────┘     │          │
                    │                    │                             │          │
                    │                    │   VBUS ────┬─── 5V          │          │
                    │                    │   VSYS ────┴─── 5V          │          │
                    │                    │                             │          │
                    │                    └─────────────────────────────┘          │
                    │                                                             │
                    │                    MICROCONTROLLER                          │
                    │                    ┌─────────────────────────────┐          │
                    │                    │                             │          │
                    │                    │   RP2040                      │          │
                    │                    │   ┌─────────────────────┐     │          │
                    │                    │   │                     │     │          │
                    │                    │                    │   │  GPIO 0 ────┬─── SIP_ENABLE  │     │          │
                    │                    │   │  GPIO 1 ────┬─── PUF_ENABLE  │     │          │
                    │                    │   │  GPIO 2 ────┬─── LED         │     │          │
                    │                    │   │  GPIO 4 ────┬─── I²C SDA     │     │          │
                    │                    │   │  GPIO 5 ────┬─── I²C SCL     │     │          │
                    │                    │   │  GPIO 6 ────┬─── INT_DRDY(opt│     │          │
                    │                    │   │  GPIO 26 ───┬─── ADC0 (alt)  │     │          │
                    │                    │   │  VCC ───────┴─── 3.3V        │     │          │
                    │                    │   │  GND ───────┴─── GND         │     │          │
                    │                    │   │                     │     │          │
                    │                    │   └─────────────────────┘     │          │
                    │                    │                             │          │
                    │                    └─────────────────────────────┘          │
                    │                                                             │
                    │                    SENSOR (populate ONE option)              │
                    │                    ┌─────────────────────────────┐          │
                    │                    │                             │          │
                    │                    │  DEFAULT: LPS28DFWTR (SMD)    │          │
                    │                    │   ┌─────────────────────┐     │          │
                    │                    │   │  VDD ────── 3.3V    │     │          │
                    │                    │   │  GND ────── GND     │     │          │
                    │                    │   │  SDA ────── GPIO 4  │     │          │
                    │                    │   │  SCL ────── GPIO 5  │     │          │
                    │                    │   │  SA0 ────── GND(0x5C│     │          │
                    │                    │   │  INT ────── GPIO 6  │     │          │
                    │                    │   └─────────────────────┘     │          │
                    │                    │  Pull-ups: 10kΩ SDA/SCL     │          │
                    │                    │  Decoupling: 100nF VDD–GND   │          │
                    │                    │                             │          │
                    │                    │  ALTERNATIVE: MPX5010DP (TH)  │          │
                    │                    │   ┌─────────────────────┐     │          │
                    │                    │   │  V+   ───── 5V(VBUS)│     │          │
                    │                    │   │  GND  ───── GND     │     │          │
                    │                    │   │  Vout─R5 10kΩ─GPIO26│     │          │
                    │                    │   │      (ADC0, divider) │     │          │
                    │                    │   └─────────────────────┘     │          │
                    │                    │  Decoupling: 100nF+10µF      │          │
                    │                    │                             │          │
                    │                    └─────────────────────────────┘          │
                    │                                                             │
                    │                    XAC / AT OUTPUTS                          │
                    │                    ┌─────────────────────────────┐          │
                    │                    │                             │          │
                    │                    │   SIP_ENABLE (GPIO 0 OUT)     │          │
                    │                    │   ┌─────────────────────┐     │          │
                    │                    │   │  GPIO 0 → PC817 opto│     │          │
                    │                    │   │  → TRRS 3.5mm jack  │     │          │
                    │                    │   │    (XAC/AT output)  │     │          │
                    │                    │   └─────────────────────┘     │          │
                    │                    │                             │          │
                    │                    │   PUF_ENABLE (GPIO 1 OUT)     │          │
                    │                    │   ┌─────────────────────┐     │          │
                    │                    │   │  GPIO 1 → PC817 opto│     │          │
                    │                    │   │  → TRRS 3.5mm jack  │     │          │
                    │                    │   │    (XAC/AT output)  │     │          │
                    │                    │   └─────────────────────┘     │          │
                    │                    │                             │          │
                    │                    └─────────────────────────────┘          │
                    │                                                             │
                    │                    STATUS LED                               │
                    │                    ┌─────────────────────────────┐          │
                    │                    │                             │          │
                    │                    │   STATUS LED                  │          │
                    │                    │   ┌─────────────────────┐     │          │
                    │                    │   │                     │     │          │
                    │                    │   │  GPIO 2 ────┬─── 220Ω │     │          │
                    │                    │   │  VCC ───────┴─── 3.3V │     │          │
                    │                    │   │  GND ───────┴─── GND   │     │          │
                    │                    │   │                     │     │          │
                    │                    │   └─────────────────────┘     │          │
                    │                    │                             │          │
                    │                    └─────────────────────────────┘          │
                    │                                                             │
                    └─────────────────────────────────────────────────────────────┘
```

## Optional Display Connectors

> Both display connectors are unpopulated by default. Footprints are provided on the PCB so either or both can be added without rework. The I²C OLED shares the existing I²C bus with the LPS28DFWTR sensor (no address conflict). The SPI color LCD uses SPI1 hardware peripheral on dedicated GPIO pins.

---

### J1 — I²C OLED Display (1", 128×64, SSD1306 or compatible)

**Connector: 4-pin 2.54 mm Dupont / JST-XH, pin order top-to-bottom**

```
    J1 — I²C OLED CONNECTOR (4-pin Dupont)
    ┌────┬──────────┬────────────────────────────────────────────┐
    │ 1  │  GND     │  Ground                                    │
    │ 2  │  VCC     │  3.3V                                      │
    │ 3  │  SCL     │  GPIO 5 — I²C bus clock (shared)          │
    │ 4  │  SDA     │  GPIO 4 — I²C bus data (shared)           │
    └────┴──────────┴────────────────────────────────────────────┘

    SHARED I²C BUS NOTE:
    ┌─────────────────────────────────────────────────────────────┐
    │  LPS28DFWTR  ──┬──  GPIO 4/5  ──┬──  J1 OLED              │
    │                │                │                          │
    │                └────────────────┴──  STEMMA QT             │
    │                                                             │
    │  I²C addresses:                                             │
    │    LPS28DFWTR: 0x5C (SA0=GND) or 0x5D (SA0=VDD)           │
    │    SSD1306 OLED: 0x3C (default) or 0x3D (ADDR pin=VCC)    │
    │    STEMMA QT devices: address depends on connected device  │
    │    → Verify no address conflicts before connecting device  │
    │                                                             │
    │  Pull-ups: 10kΩ on SDA and SCL are shared (already placed) │
    └─────────────────────────────────────────────────────────────┘

                    J1 WIRING DIAGRAM
                    ┌─────────────────────────────┐
                    │                             │
                    │   J1 (4-pin Dupont)         │
                    │   ┌─────────────────────┐   │
                    │   │                     │   │
                    │   │  GND  ────── GND    │   │
                    │   │  VCC  ────── 3.3V   │   │
                    │   │  SCL  ────── GPIO 5 │   │  (I²C0 SCL, shared)
                    │   │  SDA  ────── GPIO 4 │   │  (I²C0 SDA, shared)
                    │   │                     │   │
                    │   └─────────────────────┘   │
                    │                             │
                    │  Display: 1" 128×64 OLED    │
                    │  Controller: SSD1306         │
                    │  Supply: 3.3V               │
                    │                             │
                    └─────────────────────────────┘
```

---

### STEMMA QT — I²C Expansion Port (Adafruit STEMMA QT / Qwiic compatible)

**Connector: JST-SH 4-pin (1.0 mm pitch) — standard Adafruit STEMMA QT / SparkFun Qwiic**

```
    STEMMA QT CONNECTOR (JST-SH 4-pin, 1.0mm pitch)
    ┌────┬──────────┬────────────────────────────────────────────────┐
    │ 1  │  GND     │  Ground                                        │
    │ 2  │  V+      │  3.3V — via R8 (10kΩ series on power line)    │
    │ 3  │  SDA     │  GPIO 4 — I²C0 SDA (shared bus)              │
    │ 4  │  SCL     │  GPIO 5 — I²C0 SCL (shared bus)              │
    └────┴──────────┴────────────────────────────────────────────────┘

    R8 NOTE: A 10kΩ resistor is placed in series on the V+ power line.
    This limits inrush current and provides soft power protection for
    connected STEMMA QT breakout boards. It is not a pull-up resistor —
    the I²C pull-ups (10kΩ on SDA/SCL) are separate and already placed.

                    STEMMA QT WIRING DIAGRAM
                    ┌─────────────────────────────┐
                    │                             │
                    │   STEMMA QT (JST-SH 4-pin)  │
                    │   ┌─────────────────────┐   │
                    │   │                     │   │
                    │   │  GND  ────── GND    │   │
                    │   │  V+   ─ R8(10kΩ) ─ 3.3V│  (current-limited 3.3V)
                    │   │  SDA  ────── GPIO 4 │   │  (I²C0 SDA, shared)
                    │   │  SCL  ────── GPIO 5 │   │  (I²C0 SCL, shared)
                    │   │                     │   │
                    │   └─────────────────────┘   │
                    │                             │
                    │  Compatible: any Adafruit   │
                    │  STEMMA QT or SparkFun      │
                    │  Qwiic I²C breakout board   │
                    │  (3.3V logic, I²C)          │
                    │                             │
                    └─────────────────────────────┘

    USE CASES:
    • Plug-and-play I²C sensor expansion (IMU, RTC, colour sensor, etc.)
    • Future MPU6050 IMU connection for head-tracking (Section 10.3)
    • Any Adafruit STEMMA QT or SparkFun Qwiic module
    • Verify I²C address of connected device against bus address table
```

---

### J2 — SPI Color LCD Display (2"–4", ST7789 / ILI9341 or compatible)

**Connector: 9-pin 2.54 mm Dupont / JST-XH, pin order matches display pinout table**

**GPIO assignment — SPI1 hardware peripheral, non-analog pins:**

```
    J2 — SPI COLOR LCD CONNECTOR (9-pin Dupont)
    ┌────┬──────────────┬────────────────────────────────────────┐
    │ 1  │  VCC         │  3.3V power                            │
    │ 2  │  GND         │  Ground                                │
    │ 3  │  CS          │  GPIO 13 — SPI1 CSn (active low)      │
    │ 4  │  RESET       │  GPIO 15 — LCD reset (active low)     │
    │ 5  │  DC/RS       │  GPIO 14 — data/command select        │
    │ 6  │  SDI (MOSI)  │  GPIO 11 — SPI1 TX                    │
    │ 7  │  SCK         │  GPIO 10 — SPI1 SCK                   │
    │ 8  │  LED         │  GPIO 16 — backlight PWM (or 3.3V)    │
    │ 9  │  SDO (MISO)  │  GPIO 12 — SPI1 RX (optional)        │
    └────┴──────────────┴────────────────────────────────────────┘

    NOTE: If read-back from the display is not needed, pin 9 (SDO/MISO)
    can be left unconnected on both the PCB header and the display side.

    LED (pin 8) options:
      • Connect to GPIO 16 for software-controlled PWM brightness
      • Connect directly to 3.3V to keep backlight always on (no GPIO needed)
      PCB has solder bridge: default routes to GPIO 16; bridge for always-on.

                    J2 WIRING DIAGRAM
                    ┌─────────────────────────────────┐
                    │                                 │
                    │   J2 (9-pin Dupont)             │
                    │   ┌─────────────────────────┐   │
                    │   │                         │   │
                    │   │  VCC   ────── 3.3V      │   │
                    │   │  GND   ────── GND       │   │
                    │   │  CS    ────── GPIO 13   │   │  (SPI1 CSn)
                    │   │  RESET ────── GPIO 15   │   │  (active low)
                    │   │  DC/RS ────── GPIO 14   │   │  (data/cmd)
                    │   │  MOSI  ────── GPIO 11   │   │  (SPI1 TX)
                    │   │  SCK   ────── GPIO 10   │   │  (SPI1 SCK)
                    │   │  LED   ────── GPIO 16   │   │  (backlight PWM)
                    │   │  MISO  ────── GPIO 12   │   │  (SPI1 RX, opt.)
                    │   │                         │   │
                    │   └─────────────────────────┘   │
                    │                                 │
                    │  Display: 2"–4" color TFT LCD   │
                    │  Controller: ST7789 / ILI9341   │
                    │  Supply: 3.3V                   │
                    │  SPI bus: SPI1 hardware          │
                    │                                 │
                    └─────────────────────────────────┘

    SPI1 HARDWARE PINS SUMMARY:
    ┌───────────────────────────────────────────────────────────┐
    │  GPIO 10 ── SCK    (SPI1 SCK)                            │
    │  GPIO 11 ── MOSI   (SPI1 TX)                             │
    │  GPIO 12 ── MISO   (SPI1 RX)   optional                  │
    │  GPIO 13 ── CS     (SPI1 CSn)  driven by firmware        │
    │  GPIO 14 ── DC/RS  (GPIO out)  high=data, low=command    │
    │  GPIO 15 ── RESET  (GPIO out)  pulse low to reset        │
    │  GPIO 16 ── LED    (PWM out)   backlight brightness       │
    │                                                           │
    │  All pins are non-analog. GPIO 26–29 (ADC) are free.    │
    └───────────────────────────────────────────────────────────┘
```

---

### EXTERNAL_IO — Rotary Encoder / Button / I²C Expansion Header

**Connector: 7-pin 2.54 mm header (MA06-1 footprint)**

This connector consolidates the rotary encoder signals, push button, and I²C bus into a single header for connecting an external encoder+OLED module or control panel. The rotary encoder channels are named ROT_A/SIP and ROT_B/PUFF reflecting their firmware role — channel A triggers on sip detection, channel B on puff detection.

```
    EXTERNAL_IO CONNECTOR (7-pin 2.54mm header)
    ┌────┬──────────────┬────────────────────────────────────────────┐
    │ 1  │  BUTTON      │  GPIO 20 — rotary encoder push button     │
    │ 2  │  ROT_A/SIP   │  GPIO 18 — rotary encoder channel A       │
    │ 3  │  ROT_B/PUFF  │  GPIO 19 — rotary encoder channel B       │
    │ 4  │  SCL         │  GPIO 5  — I²C0 SCL (shared bus)         │
    │ 5  │  SDA         │  GPIO 4  — I²C0 SDA (shared bus)         │
    │ 6  │  3.3V        │  3.3V power                               │
    │ 7  │  GND         │  Ground                                   │
    └────┴──────────────┴────────────────────────────────────────────┘

                    EXTERNAL_IO WIRING DIAGRAM
                    ┌──────────────────────────────────────┐
                    │                                      │
                    │   EXTERNAL_IO (7-pin header)         │
                    │   ┌────────────────────────────┐     │
                    │   │                            │     │
                    │   │  BUTTON ────── GPIO 20     │     │  (active low, pull-up in fw)
                    │   │  ROT_A  ────── GPIO 18     │     │  (SIP channel)
                    │   │  ROT_B  ────── GPIO 19     │     │  (PUFF channel)
                    │   │  SCL    ────── GPIO 5      │     │  (I²C shared)
                    │   │  SDA    ────── GPIO 4      │     │  (I²C shared)
                    │   │  3.3V   ────── 3.3V        │     │
                    │   │  GND    ────── GND         │     │
                    │   │                            │     │
                    │   └────────────────────────────┘     │
                    │                                      │
                    │  Typical use: rotary encoder module  │
                    │  with integrated push button and     │
                    │  I²C OLED (SSD1306) on same header   │
                    │                                      │
                    └──────────────────────────────────────┘

    ROTARY ENCODER NOTES:
    • ROT_A (GPIO 18) and ROT_B (GPIO 19) are quadrature encoder inputs
    • Channel naming (SIP/PUFF) reflects firmware mapping —
      clockwise rotation = sip-direction events, CCW = puff-direction
    • BUTTON (GPIO 20) is the encoder shaft push button — configure
      with internal pull-up in firmware (active low)
    • I²C pins (4 & 5) on this connector share the bus with
      LPS28DFWTR, J1 OLED, and STEMMA QT — verify address of
      any device connected here
```

---

### Full GPIO Allocation Map (updated)

```
    PICO W GPIO ALLOCATION
    ┌────────┬──────────────────────────────────────────────────┐
    │ GPIO 0 │  SIP_ENABLE output → PC817 opto → TRRS 3.5mm jack (XAC/AT) │
    │ GPIO 1 │  PUF_ENABLE output → PC817 opto → TRRS 3.5mm jack (XAC/AT) │
    │ GPIO 2 │  Status LED (onboard / external)                 │
    │ GPIO 3 │  [reserved]                                      │
    │ GPIO 4 │  I²C0 SDA — LPS28DFWTR + J1 OLED + STEMMA QT (shared bus) │
    │ GPIO 5 │  I²C0 SCL — LPS28DFWTR + J1 OLED + STEMMA QT (shared bus) │
    │ GPIO 6 │  INT_DRDY — LPS28DFWTR interrupt (optional)     │
    │ GPIO 7 │  [reserved]                                      │
    │ GPIO 8 │  [reserved]                                      │
    │ GPIO 9 │  [reserved]                                      │
    │ GPIO 10│  SPI1 SCK  — J2 color LCD SCK                   │
    │ GPIO 11│  SPI1 TX   — J2 color LCD MOSI/SDI              │
    │ GPIO 12│  SPI1 RX   — J2 color LCD MISO/SDO (optional)   │
    │ GPIO 13│  SPI1 CSn  — J2 color LCD CS                    │
    │ GPIO 14│  GPIO out  — J2 color LCD DC/RS                  │
    │ GPIO 15│  GPIO out  — J2 color LCD RESET                  │
    │ GPIO 16│  PWM out   — J2 color LCD backlight LED          │
    │ GPIO 17│  [reserved]                                      │
    │ GPIO 18│  ROT_A/SIP  — rotary encoder channel A (EXTERNAL_IO pin 2) │
    │ GPIO 19│  ROT_B/PUFF — rotary encoder channel B (EXTERNAL_IO pin 3) │
    │ GPIO 20│  BUTTON     — rotary encoder push button (EXTERNAL_IO pin 1) │
    │GPIO 21-│                                                  │
    │GPIO 25 │  [reserved for future expansion]                 │
    │ GPIO 26│  ADC0 — MPX5010DP analog (alternative sensor) via R5 10kΩ │
    │ GPIO 27│  ADC1 — [reserved]                               │
    │ GPIO 28│  ADC2 — [reserved]                               │
    │ GPIO 29│  ADC3 — [reserved / VSYS sense on Pico W]       │
    └────────┴──────────────────────────────────────────────────┘
```

---

## Component List

### Power Supply Components:
- **3.3V LDO Regulator** (e.g., LM1117-3.3 or similar)
- **Input Voltage (VIN)**: 5V
- **Output Voltage**: 3.3V
- **Capacitors**: 100μF (input), 10μF (output)

### Microcontroller Components:
- **Raspberry Pi Pico W** (RP2040 + CYW43439)
- **GPIO Pins used**: 0 (SIP_ENABLE out), 1 (PUF_ENABLE out), 2 (LED), 4 (I²C SDA), 5 (I²C SCL), 6 (INT_DRDY opt.), 10–16 (SPI color LCD), 18 (ROT_A/SIP), 19 (ROT_B/PUFF), 20 (BUTTON), 26 (ADC0 alt.)
- **Power Pins**: VBUS, VSYS, GND

### Sensor Components (populate ONE — both footprints on initial PCB):

**DEFAULT — LPS28DFWTR (SMD, I²C):**
- **LPS28DFWTR** CCLGA-7L, STMicroelectronics
- **Interface**: I²C — GPIO 4 (SDA), GPIO 5 (SCL)
- **I²C address**: 0x5C (SA0 → GND) or 0x5D (SA0 → VDD)
- **INT_DRDY**: GPIO 6 (optional data-ready interrupt)
- **Pull-up Resistors**: 10kΩ on SDA and SCL to 3.3V
- **Decoupling Cap**: 100nF ceramic between VDD and GND
- **Supply**: 3.3V (1.7–3.6V range)

**ALTERNATIVE — MPX5010DP (Through-Hole, Analog):**
- **MPX5010DP** SIP-6, NXP/Freescale
- **Interface**: Analog voltage → R5 (10kΩ) → GPIO 26 (ADC0); **NOT I²C**
- **Supply**: **5V (VBUS)** — full output range 0.2V–4.7V
- **Voltage divider**: R5 (10kΩ, top leg) + ~20kΩ pull-down to GND scales Vout to ≤3.3V for ADC safety
- **Decoupling Caps**: 100nF + 10µF on supply pins

### XAC / AT Output Components:
- **SIP_ENABLE output**: GPIO 0 → PC817SC optocoupler → TRRS 3.5mm jack (SIP output to XAC or AT device)
- **PUF_ENABLE output**: GPIO 1 → PC817SC optocoupler → TRRS 3.5mm jack (PUFF output to XAC or AT device)
- **Optocouplers**: 2× PC817SC / DPC817S-X-TRSL-4 (one per channel)
- **TRRS Jacks**: 2× TRRS_2SWITCH_PJ332A (3.5mm, TRRS)
- **Note**: Sip/puff is **detected** by the pressure sensor (LPS28DFWTR or MPX5010DP), not by these GPIOs

### Output Components:
- **Status LED**: GPIO 2
- **Current Limiting Resistor**: 220Ω
- **LED Color**: Green (optional: Red or Blue)

### EXTERNAL_IO Connector Components:
- **Connector**: 7-pin 2.54 mm header (MA06-1)
- **BUTTON**: GPIO 20 — rotary encoder push button (active low, firmware pull-up)
- **ROT_A/SIP**: GPIO 18 — rotary encoder channel A
- **ROT_B/PUFF**: GPIO 19 — rotary encoder channel B
- **SCL / SDA**: GPIO 5 / GPIO 4 — I²C shared bus
- **Power**: 3.3V and GND
- **ESD Protection**: SP724AHTG TVS array IC on signal lines (BUTTON, ROT_A, ROT_B, SDA, SCL)

### STEMMA QT I²C Expansion Connector:
- **Connector**: JST-SH 4-pin (1.0 mm pitch) — STEMMA QT / Qwiic standard
- **Interface**: I²C shared bus — GPIO 4 (SDA), GPIO 5 (SCL)
- **Power**: 3.3V via R8 (10kΩ series resistor for inrush protection)
- **Compatible with**: Any Adafruit STEMMA QT or SparkFun Qwiic I²C module (3.3V logic)
- **Planned use**: IMU (MPU6050) for head-tracking expansion (see Section 10.3 of reference doc)

### Optional Display Connector Components:

**J1 — I²C OLED (4-pin Dupont, unpopulated by default):**
- **Connector**: 4-pin 2.54 mm Dupont / JST-XH header on PCB
- **Display**: 1" 128×64 OLED (SSD1306 or compatible)
- **Interface**: I²C shared bus — GPIO 4 (SDA), GPIO 5 (SCL)
- **I²C address**: 0x3C (default) or 0x3D
- **Supply**: 3.3V

**J2 — SPI Color LCD (9-pin Dupont, unpopulated by default):**
- **Connector**: 9-pin 2.54 mm Dupont / JST-XH header on PCB
- **Display**: 2"–4" color TFT LCD (ST7789 / ILI9341 or compatible)
- **Interface**: SPI1 hardware — GPIO 10 (SCK), 11 (MOSI), 12 (MISO), 13 (CS), 14 (DC/RS), 15 (RESET), 16 (LED/backlight)
- **Supply**: 3.3V
- **Backlight**: GPIO 16 (PWM) or solder bridge to always-on 3.3V

### Circuit Protection Components:
- **IC**: SP724AHTG — Low-capacitance TVS diode array (STMicroelectronics)
- **Purpose**: ESD and transient overvoltage protection on I/O lines not covered by the PC817 opto-isolators
- **Protected lines**: EXTERNAL_IO connector signals (BUTTON / GPIO 20, ROT_A / GPIO 18, ROT_B / GPIO 19, SDA / GPIO 4, SCL / GPIO 5); additional placement on STEMMA QT and display connector lines as needed
- **Note**: GPIO 0 and GPIO 1 (SIP_ENABLE / PUF_ENABLE) are opto-isolated via PC817SC and do not require the SP724AHTG

### Rubber Chicken Interface Components:
- **Sip Interface**: Mechanical connection for suction
- **Blow Interface**: Mechanical connection for blowing
- **Status Indicator**: LED for system status

## Key Features:

1. **Power Management**: 5V input to 3.3V output
2. **Dual Sensor Support**: LPS28DFWTR (SMD, I²C default) or MPX5010DP (through-hole, analog ADC alternative) — both footprints on initial PCBs
3. **I²C Communication**: LPS28DFWTR on GPIO 4 (SDA) / GPIO 5 (SCL) at address 0x5C — 24-bit, 0.32 Pa noise, water-resistant
4. **ADC Input (alternative)**: MPX5010DP analog Vout via R5 (10kΩ divider) on GPIO 26 (ADC0); supplied from 5V
5. **XAC / AT Outputs**: GPIO 0 (SIP_ENABLE) and GPIO 1 (PUF_ENABLE) drive PC817SC optocouplers → TRRS 3.5mm jacks for Xbox Adaptive Controller or AT device integration; sip/puff detection is done by the pressure sensor, not these GPIOs
6. **Status Output**: LED indicator on GPIO 2
7. **EXTERNAL_IO Connector**: 7-pin header combining rotary encoder (GPIO 18 ROT_A/SIP, GPIO 19 ROT_B/PUFF), push button (GPIO 20), and I²C bus (GPIO 4/5) + 3.3V/GND — connects rotary encoder module with optional integrated OLED
8. **STEMMA QT I²C Expansion Port**: JST-SH 4-pin connector on shared I²C bus (GPIO 4/5); 3.3V power via R8 (10kΩ); compatible with any Adafruit STEMMA QT or SparkFun Qwiic module — primary expansion point for future IMU head-tracking
9. **Optional I²C OLED Display (J1)**: 4-pin Dupont connector; 1" 128×64 SSD1306 shares I²C bus with LPS28DFWTR (addresses 0x3C vs 0x5C — no conflict)
10. **Optional SPI Color LCD (J2)**: 9-pin Dupont connector; 2"–4" ST7789/ILI9341 on dedicated SPI1 hardware pins (GPIO 10–16); backlight PWM on GPIO 16
11. **Rubber Chicken Interface**: Mechanical connections for sip/puff demonstration
12. **Low Power Consumption**: LPS28DFWTR idles at 1.7 µA; overall system target < 10 mA standby (displays off)
13. **Real-time Processing**: Pico W RP2040 handles I²C polling, ADC sampling, signal filtering, USB HID output, and optional display rendering
14. **Circuit Protection**: SP724AHTG TVS array IC on all external-facing I/O lines not protected by the PC817 opto-isolators (EXTERNAL_IO connector: GPIO 18/19/20/4/5; STEMMA QT and display connector lines as applicable)
15. **Under Consideration — microSD Data Logging**: 4 free GPIOs (21–24) reserved as candidate pins for a software SPI microSD card reader; see expansion notes below

This schematic documents both sensor options in a dual-footprint design. The LPS28DFWTR I²C sensor is the default for production use; the MPX5010DP through-hole option remains available for prototyping without SMD tooling. Both display connectors (J1 I²C OLED and J2 SPI color LCD) are built into the PCB hardware but unpopulated — enabling future display support without board redesign.

---

## Future Expansion Considerations

### 💡 microSD Card Reader — Usage Data Logging

> **Difficulty:** Easy — standard SPI peripheral, well-supported libraries on RP2040
> **Status:** Under consideration — hardware GPIO slots are available; usefulness of logged data is an open question and the primary reason this has not been committed to the design yet

#### Hardware

A microSD card module connects via SPI. SPI1 is already occupied by the color LCD, so a software SPI implementation on free GPIOs is the clean approach. The following pins are proposed:

```
    microSD CANDIDATE GPIO ASSIGNMENT (software SPI)
    ┌────────┬───────────┬──────────────────────────────────────┐
    │ GPIO 21│  SD_CS    │  Chip select (active low)            │
    │ GPIO 22│  SD_SCK   │  SPI clock                           │
    │ GPIO 23│  SD_MOSI  │  SPI data out (to card)              │
    │ GPIO 24│  SD_MISO  │  SPI data in (from card)             │
    └────────┴───────────┴──────────────────────────────────────┘

    Supply: 3.3V (most microSD modules include onboard 3.3V regulator
            and level shifting — verify before connecting directly)
    Remaining free GPIOs after this assignment: 17, 25
```

Software SPI at 1–4 MHz is perfectly adequate for logging purposes on the RP2040. The `sdcard.py` MicroPython driver or the C SDK FatFS port both support this configuration.

#### The Real Question — What Is Worth Logging?

The hardware cost and code complexity are both low. The harder question is whether the logged data generates actionable insight. Items currently under discussion:

| Data Point | What It Could Tell Us | Useful? |
|---|---|---|
| Sip/puff event count per session | Total usage volume; fatigue patterns over time | Likely yes — rehab reporting |
| Pressure magnitude at each event | Whether user breath strength is changing; calibration drift | Probably yes |
| Hard vs soft sip/puff ratio | How often user hits each threshold tier | Maybe — depends on firmware tiers |
| Time between events (inter-event interval) | Response time, fatigue, or tremor patterns | Interesting for clinical research |
| Session start/end timestamps | Daily usage patterns | Yes — needs RTC or WiFi time sync |
| False trigger count | Sensor noise or threshold calibration issues | Yes — firmware quality metric |
| Config/threshold changes | How often and which direction user adjusts | Yes — UX feedback |
| Operating mode (USB HID / BLE / gamepad) | Which mode gets used most | Yes — informs future dev priority |
| Pressure sensor temperature (LPS28DFWTR has onboard temp) | Correlate performance with ambient conditions | Low priority |

#### Discussion Points

- **Who benefits from the log?** Clinicians and therapists tracking patient progress would benefit most. The user themselves less so unless there is a display showing trends.
- **Privacy** — usage logs are potentially sensitive health data. If the device logs to SD, what is the data retention and access policy? Should logging be opt-in?
- **Without a real-time clock (RTC)**, timestamps are only relative to power-on, which limits usefulness for session-based reporting. A simple DS3231 or PCF8523 RTC module on the STEMMA QT port would solve this at ~$2 additional BOM cost.
- **Log format** — CSV is the simplest (human-readable, importable into spreadsheets for rehab reporting). Binary is more compact. JSON is most flexible.
- **Trigger for logging** — log every event? Every session summary on power-off? Configurable interval?

> **Next step:** Decide whether there is a concrete use case (e.g. therapist download, user self-monitoring, research data collection) that justifies the SD slot. If yes, reserve GPIO 21–24 on the PCB as unpopulated test points so a future board revision can add the connector without a full respin.

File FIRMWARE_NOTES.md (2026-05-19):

# SipNPuff Firmware Notes

**Date of last update:** 2026-05-18
**Source tree:** `~/claude/coder/SipAndPuff/source/`
**Verified hardware:** RP2350 Pico 2 (UID `977F4E5A5C8CEE36`),
RP2040 Pico (UID `E4624881D3163931`). Both run CircuitPython 10.2.0.

This document captures the firmware state after the bring-up work
done in May 2026 — pressure-sensor fusion, IMU pointing, adaptive
threshold tuning, the 4-cell event-indicator HUD, the direct-kPa
repeat-rate map, LPS28 baseline auto-rezero, per-direction signal
scaling, and a configurable encoder drive mode.

---

## 1. Hardware variants the firmware understands

Only one variant key today: **`pico2_mpx5010dp`** (defined in
`hardware_config.VARIANTS`). The name is historical — it works on
both Pico (RP2040) and Pico 2 (RP2350) boards. Pin map:

| Function | Pin | Notes |
|---|---|---|
| MPX5010DP ADC | `GP26` | analog differential, 0-10 kPa **unidirectional** |
| Encoder A / B / btn | `GP18` / `GP19` / `GP20` | quadrature + shaft pushbutton |
| Encoder button 2 | `GP21` | short-sip → momentary closure |
| XAC opto puff / sip | `GP1` / `GP0` | dry-contact pulse outputs |
| I²C SDA / SCL | `GP4` / `GP5` | J1 connector |
| Display SPI | `GP10–GP16` | J2; ST7735R or other LCDs |

**I²C peripherals on J1** (auto-detected on boot):

- **SSD1306 OLED** at `0x3C` — monochrome, 128×64.
- **LPS28DFW** at `0x5C` — absolute pressure, 260–1260 hPa,
  ±~60 kPa from atmospheric. Bidirectional. **This is the sensor
  the classifier reads from by default.**
- **BNO08x IMU** at `0x4A` or `0x4B` — for head-tracking mouse mode.
- (Future: BNO055 at `0x28`/`0x29` — driver included, not used here.)

---

## 2. Pressure sensing — why we don't use the MPX for sip

The on-board MPX5010DP is a **0–10 kPa unidirectional** sensor. Below
0 kPa its output voltage saturates near its offset, which decodes
to roughly **−0.3 to −0.4 kPa apparent pressure regardless of how
hard the user sips**. Documented at length in
`~/.claude/projects/.../memory/project_mpx5010dp_sip_limit.md`.

**Current solution:** the LPS28DFW is plumbed to the mouthpiece, and
the classifier reads both branches from it:

```
puff_from_lps28 = true
sip_from_lps28  = true
```

Internally, `sip_puff_device._run_normal` builds a fused signal:

```python
classifier_p = max(puff_branch, 0) + min(sip_branch, 0)
```

…where each *branch* independently picks MPX or LPS28 based on the
two flags. With both true, `classifier_p == lps_gauge`. With only
`sip_from_lps28 = true`, MPX drives puff and LPS28 drives sip
(historical "fusion" mode).

The MPX is still read every loop and shown on the display so the
operator can spot a sensor failure, but it doesn't feed the event
classifier in the current configuration.

### Per-direction signal scaling

Empirically puff takes ≈ 2× the lung effort of sip on this plumbing,
so the firmware applies a per-direction scale **before** the
classifier sees the value:

```
classifier_p = max(puff_branch, 0) * puff_signal_scale
             + min(sip_branch,  0) * sip_signal_scale
```

Defaults: `puff_signal_scale = 2.0`, `sip_signal_scale = 1.0`. The
display threshold-tick on the puff bargraph is moved to
`puff_on_kpa / puff_signal_scale` so the visual tick matches where
the firmware actually triggers.

A planned **user-calibration mode** would derive these scales from
a guided "do your hardest puff / hardest sip" sequence — see the
memory `project_signal_scale_calibration.md`.

### LPS28 baseline auto-rezero

The LPS28 baseline captured at boot can drift over minutes — room
pressure, thermal settling, slow mouthpiece leaks. The firmware now
watches for a stable-idle interval and re-snaps the baseline when:

- `state == "idle"` continuously for `lps_auto_rezero_idle_s` (default 30 s)
- LPS gauge spread (max − min) over that window is < 100 Pa
- Mean drift exceeds `lps_auto_rezero_threshold_kpa` (default 0.5 kPa)

When all three hold, `LPS28Sensor.recenter_now()` is invoked and a
line like `LPS28: auto-rezero (idle 30.0s, drift -1.640kPa,
spread 0.016kPa)` is printed. Setting `lps_auto_rezero_idle_s = 0`
disables the feature. The `recenter_now()` method is also callable
from the REPL for manual triggering.

---

## 3. Breath-event state machine (`breath_classifier.py`)

States: `IDLE → PUFF_ON / SIP_ON → PUFF_PEND / SIP_PEND → IDLE`.

Hysteresis is **static** (`puff_off_kpa` / `sip_off_kpa`) since we
moved to the LPS28. The adaptive-release scheme is wired in for
reference but disabled by default:

```
adaptive_release_enabled = false
```

It fired false releases when a held breath's noise dipped below
peak − min_gap; the static hysteresis is robust at the ±0.7 kPa
release threshold against ±0.02 kPa noise.

### Event semantics

| Event | Trigger | Encoder mode | Mouse mode |
|---|---|---|---|
| `puff` | Quick puff, released within `puff_hold_to_repeat_s` | `enc.press()` (GP20) | left click |
| `sip` | Quick sip, released within `sip_hold_to_repeat_s` | `enc.press2()` (GP21) | right click |
| `puff_repeat` | Held puff past hold-window, fires at pressure-scaled rate  | one CW click per tick | scroll up tick  |
| `sip_repeat` | Held sip, same idea | one CCW click per tick | scroll down tick|
| `double_puff` | Two puffs within `double_puff_window_s` | CW + double XAC pulse | middle click |
| `double_sip` | Two sips within `double_sip_window_s` | double XAC sip pulse only | (no-op) |

XAC opto pulses fire in encoder mode alongside every CW/CCW
rotation tick as well as the short puff/sip presses — so a wired
XAC consumer sees the same activity as the encoder consumer.

### Post-scroll release-suppression

When the user releases after a sustained scroll, the classifier
**suppresses** the `puff`/`sip` event so they don't get a spurious
"select" at the end of every scroll. Tracked via `_repeat_emitted`
in the state machine: True after any `*_repeat` fires, reset on
the next state entry.

### Per-direction tap window

`puff_hold_to_repeat_s` and `sip_hold_to_repeat_s` are independent.
Both default to **0.5 s** since the LPS28 gives symmetric clean
readings. Raise one if accidental scrolls happen during deliberate
taps; lower for earlier scroll trigger.

---

## 4. Repeat-rate map — 1 : 1 kPa → Hz

Rewritten on 2026-05-17. Per-tick rate is now:

```
rate_hz = clamp(magnitude_kpa * repeat_rate_factor,
                repeat_min_hz, repeat_max_hz)
```

…with `magnitude_kpa` clamped above by `repeat_full_scale_kpa`.

Defaults give a clean 1 : 1 mapping:

- 1 kPa held breath → 1 Hz
- 5 kPa → 5 Hz
- 10 kPa → 10 Hz
- ≥10 kPa → 10 Hz (clamped)

Bump `repeat_rate_factor` above 1 for faster scrolling per kPa of
effort. A **logarithmic** option is planned (`repeat_rate_curve`)
but not yet implemented — see the inline TODO in
`breath_classifier._tick_period` and the
`project_log_repeat_curve.md` memory.

---

## 5. Display HUD layout

LCD path (color, via `displayio` + `adafruit_st7735r` etc.):

```
+-------------------------------------------------------+
|  T-Rex Sip-N-Puff               state: idle           |
|                                                       |
|  MPX P [█████------------]  3.42                      |
|  MPX S [█----------------]  0.00                      |
|  LPS P [██████-----------]  4.10                      |
|  LPS S [█----------------]  0.00                      |
|                                                       |
|    UP    DN    SIP   PUF                              |
|   [▓▓]  [▓▓]  [▓▓]  [▓▓]                              |
+-------------------------------------------------------+
```

Mono path (SSD1306): same four rows of MPX P / MPX S / LPS P / LPS S
without the event-box row.

### Fill bars: vectorio.Rectangle, NOT display_shapes.Rect

Important gotcha: `adafruit_display_shapes.Rect` in current bundle
releases has a **read-only** `.width`. Trying to mutate it silently
fails and the bars stay frozen at 1 px. Fix landed in
`_build_color_scene._build_row`: the *outline* is still a `Rect`,
but the *fill* is a `vectorio.Rectangle` whose `.width` is mutable.

### Event-indicator boxes

The four bottom boxes are driven by `display.flash(name)` calls from
the dispatcher in `sip_puff_device.py`. Visibility rules:

| Box | Trigger event | Visibility |
|---|---|---|
| `puff_click` | `puff`, `double_puff` | Solid for `_box_click_on_s` (1 s) after the event. |
| `sip_click`  | `sip`, `double_sip` | Same. |
| `up` | `puff_repeat` | **Toggles** state per event. Forced off after `_box_stream_off_s` (0.5 s) of silence. |
| `down` | `sip_repeat` | Same toggle behavior. |

The toggle gives **≈50 % off-time naturally** at any rate the
display refresh can keep up with. At extremely high repeat rates
(>~10 Hz with a 10 Hz refresh), the toggle can blur — that's a
known limit, called out in the inline comment.

### Hardware-specific display overrides

The ST7735R 1.8" panel on the RP2040 prototype needs three extra
lines in its `/CIRCUITPY/config.txt`:

```
display_rotation = 90        # 180° from variant default of 270
display_width    = 160       # adafruit_st7735r returns native portrait dims
display_height   = 128       # — force the scene math to the rotated landscape
display_lps_full_scale_kpa = 10.0   # was 0.1, way too tight for real plumbing
```

These are **per-device** and are appended to `config.txt` at deploy
time on that device only. The source `config.txt` defaults to
`display = none` so a fresh CIRCUITPY drive doesn't try to talk to
hardware that isn't there.

---

## 5b. Encoder output drive mode

Configurable via `encoder_drive_mode`:

| Value | High state | Low state | Notes |
|---|---|---|---|
| `push_pull` (default) | Actively driven to 3.3 V | Actively driven to 0 V | Stiff output; fights any host pull-up. Works against any host. |
| `simulated_pullup` | Internal pull-up (~50 kΩ to 3.3 V), high-Z otherwise | Actively driven to 0 V | Emulates a real mechanical encoder switch — line idles high via the soft pull-up, snaps low only while pressed. |
| `open_drain` | High-Z, no internal pull | Actively driven to 0 V | Host must supply its own pull-up. Safer interop with a 5 V host. |

Applies to all four encoder output lines (A, B, BTN, BTN2). The
`simulated_pullup` and `open_drain` paths don't rely on
CircuitPython's `DriveMode.OPEN_DRAIN` — they manage high-Z by
flipping `direction` between `OUTPUT` (low) and `INPUT` (high-Z),
because the documented `DriveMode.OPEN_DRAIN` on RP2040 has been
observed leaving the line in an undefined state for the "low" half
of the cycle on this CP build. See the `_OpenDrainOutput` class in
`encoder_emulator.py`.

Boot log prints the active mode:

```
Encoder: A=GP18 B=GP19 BTN=GP20 (phase=0.0020s, drive=push_pull, protocol=pulse_encoder)
```

## 5c. Encoder click protocol

Configurable via `encoder_protocol`:

| Value | CW click action | CCW click action |
|---|---|---|
| `pulse_encoder` (default) | Pulses **A only** low for `encoder_button_press_s` (50 ms) | Pulses **B only** low for the same window |
| `5_phase_encoder` | Full gray-code quadrature sequence on A+B (5 phases × `encoder_phase_s`) | Mirror sequence |

`pulse_encoder` is the default because the **Xbox Adaptive
Controller and similar dry-contact hosts read each wire as an
independent momentary switch** — they don't decode rotary-encoder
quadrature. Each click becomes one button press on the destination
wire. For hosts that *do* decode quadrature (the T-Rex Talker's
encoder header, generic encoder breakouts), switch to
`5_phase_encoder`.

BTN and BTN2 are always pulsed regardless of protocol.

### Folding BTN2 onto BTN

For hosts with only **one** "select" input, set
`map_both_clicks_to_encoder_button = true`. Then `press2()` (short
sip) drives BTN (GP20) instead of BTN2 (GP21) — both short-puff and
short-sip register as the same press. Default `false`.

---

## 6. IMU pointing (mouse-mode only)

`imu_bno08x.py` (and parallel `imu_bno055.py`) drive an optional
9-DoF sensor. In mouse mode the gyro produces relative
`(dx, dy)` deltas, and the quaternion provides absolute yaw/pitch.

Tuning lives under the `imu_pointing_*` keys in `config.txt`:

- `imu_pointing_gain` — overall scale (default 400)
- `imu_pointing_alpha` — IIR LP on the rate stream (0.4)
- `imu_pointing_accel_expo` — power-curve exponent (1.0 = linear)
- `imu_pointing_max_per_tick` — clamp (60, ≤ HID int8 range)
- `imu_yaw_axis` / `imu_pitch_axis` — which gyro axis is which,
  with optional `+`/`-` sign prefix (e.g. `-z`)
- `imu_pointing_stillness_recenter_s` — auto re-zero after idle

The IMU isn't connected on either current bench device; the lines
in the heartbeat read `imu1=ABSENT …` and the firmware doesn't
fire mouse motion.

---

## 7. Heartbeat line on USB-CDC

Column-aligned, default cadence 2 s. Width ≈ 230 chars — needs a
wide terminal. Fields, in order:

```
t=NNNNN.NN | mpx=±N.NNN abs=±N.NNN | lps=NNN.NNN g=±N.NNNN
| peak(puf=±NN.NN,sip=±NN.NN)  ← max/min classifier input
                                 since the previous heartbeat
| imu1=… | rate(±NNN,±NNN) abs(±NNN.NN,±NNN.NN) | state=NAME
```

Set `heartbeat_period_s = 0.2` for benchtop tuning, `10–30` for
long monitors.

---

## 8. Config-key reference (selected)

Whitelist lives in `hardware_config._USER_OVERRIDABLE`. New keys
added during this work, grouped:

### Mode + I/O
- `output_mode = encoder | mouse`
- `mouse_motion_min_per_tick`, `mouse_scroll_per_repeat`

### Sensor source
- `i2c_pressure = lps28`
- `i2c_imu_1..4 = bno085 | bno086 | bno080 | bno055 | none[@0xNN]`
- `puff_from_lps28`, `sip_from_lps28` — fusion switches
- `puff_signal_scale`, `sip_signal_scale` — per-direction effort scale
- `lps_auto_rezero_idle_s` (default 30), `lps_auto_rezero_threshold_kpa` (0.5) — LPS baseline self-correction

### Display
- `display = ssd1306 oled 128x64 | st7735r color lcd 128x160 greentab | … | none`
- `display_lps_full_scale_kpa` — bar full-scale for LPS row

### Breath thresholds + timing
- `puff_on_kpa`, `puff_off_kpa`, `sip_on_kpa`, `sip_off_kpa`
- `puff_hold_to_repeat_s`, `sip_hold_to_repeat_s` (per-direction)
- `puff_repeat_multiplier`, `sip_repeat_multiplier`
- `adaptive_release_enabled`, `adaptive_release_fraction`,
  `adaptive_release_min_gap_kpa`

### Repeat-rate map (new)
- `repeat_min_hz` (1.0), `repeat_max_hz` (10.0)
- `repeat_full_scale_kpa` (10.0)
- `repeat_rate_factor` (1.0)
- `repeat_rate_curve` (`linear` / future `logarithmic`)

### Encoder outputs
- `encoder_drive_mode = push_pull | simulated_pullup | open_drain` (default `push_pull`)
- `encoder_protocol = pulse_encoder | 5_phase_encoder` (default `pulse_encoder`)
- `map_both_clicks_to_encoder_button = true | false` (default `false`)

### Pointing (mouse mode)
- `imu_pointing_gain`, `imu_pointing_alpha`,
  `imu_pointing_accel_expo`, `imu_pointing_max_per_tick`,
  `imu_pointing_stillness_recenter_s`,
  `imu_yaw_axis`, `imu_pitch_axis`

---

## 9. Known limits / next steps

- **Logarithmic repeat-rate curve** — config stub exists; formula
  sketched in `_tick_period`; not implemented. See
  `project_log_repeat_curve.md` memory.
- **IMU plumbing** — neither bench unit has a BNO08x wired in
  right now. Mouse mode is functional in code but un-exercised on
  the bench since 2026-05-10.
- **MPX5010DP retirement** — once the LPS28 plumbing is the
  permanent solution, the MPX could be dropped entirely or
  swapped for a **bidirectional MPXV7007DP** (±7 kPa, pin-compatible).
- **Box-row at very high event rates** — the toggle scheme on
  UP/DN can blur at >10 Hz events. Acceptable per user feedback;
  could enforce a min-cycle if needed.
- **Single hardware variant** — the variant key only branches on
  pin map / sensor defaults right now. If we add the MPXV7007DP
  build it'll become a second `VARIANTS` entry.

---

## 10. Deploy workflow

```bash
DEST=/media/trex/CIRCUITPY      # or CIRCUITPY1 — whichever the device mounts as
SRC=~/claude/coder/SipAndPuff/source
BUNDLE=~/adafruit-circuitpython-bundle-10.x-mpy-20260317

# Libraries (only if missing)
cp -r $BUNDLE/lib/adafruit_hid    $DEST/lib/
cp -r $BUNDLE/lib/adafruit_bno08x $DEST/lib/
cp    $BUNDLE/lib/adafruit_bno055.mpy $DEST/lib/
# (plus adafruit_lps28.mpy, adafruit_displayio_ssd1306.mpy, etc.
# depending on which display + sensors are on the unit)

# Modules + config + code.py last so the reload sees a complete tree
for f in hardware_config.py pressure_sensor.py breath_classifier.py \
         encoder_emulator.py xac_output.py display_manager.py \
         lps28_sensor.py imu_bno08x.py imu_bno055.py mouse_output.py \
         mini_st7735.py diagnostic.py sip_puff_device.py; do
    cp "$SRC/$f" "$DEST/$f"
done
cp "$SRC/config.txt" "$DEST/config.txt"

# Per-device overrides (LCD vs OLED, rotation, etc.) — sed in-place
# at deploy time. See section 5 above.

cp "$SRC/code.py" "$DEST/code.py"
sync
```

After deploy, soft-reboot via REPL (`\x02\x03\x04`) and watch
`/dev/ttyACM*` for the boot banner. The `Config: NN user override(s)
applied` line tells you how many config keys took effect — if it's
lower than expected, a key is misspelled or not whitelisted.

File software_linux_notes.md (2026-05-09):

# T-Rex Sip-N-Puff — Linux Software Development Notes

## Project Overview

CircuitPython firmware for the T-Rex Sip-N-Puff HID: a Raspberry Pi Pico-based sip and puff human interface device targeting the Xbox Adaptive Controller (XAC). Core function is reading a differential pressure sensor, classifying breath events (sip/puff/double-puff), and driving isolated dry-contact outputs to the XAC via optocouplers. Optional I2C display for status/feedback.

---

## Hardware Pin Map

| GPIO | Board Const | Function | Notes |
|---|---|---|---|
| GP4  | `board.GP4`  | I2C SDA | Optional display |
| GP5  | `board.GP5`  | I2C SCL | Optional display |
| GP16 | `board.GP16` | XAC_PUFF output | PC817 opto, drives 3.5mm jack tip |
| GP17 | `board.GP17` | XAC_SEL output | PC817 opto, drives second 3.5mm jack |
| GP18 | `board.GP18` | ENC_A | Rotary encoder phase A |
| GP19 | `board.GP19` | ENC_B | Rotary encoder phase B |
| GP20 | `board.GP20` | ENC_BTN | Encoder push button |
| GP26 | `board.GP26` | ADC0 — pressure in | MPX5010DP via 10kΩ/20kΩ voltage divider |

### Voltage Divider (pressure sensor protection)
MPX5010DP Vout max = 4.7V; Pico ADC max = 3.3V.
- Sensor VOUT → 10kΩ → GP26 → 20kΩ → GND
- Scales 4.7V → ~3.13V. Safe for RP2040 ADC.

### XAC Optocoupler Wiring (PC817)
- GP16/GP17 → 220Ω → PC817 pin 1 (Anode)
- PC817 pin 2 (Cathode) → GND
- PC817 pin 4 (Collector) → 3.5mm Tip
- PC817 pin 3 (Emitter) → 3.5mm Sleeve
- XAC sees a dry-contact switch closure — no voltage from Pico side crosses to XAC side.

---

## Toolchain Setup (one-time, on the Linux machine)

```bash
# Flash tool and library manager
sudo pip3 install mpremote circup

# Serial port access — add your user to dialout, then log out/in
sudo usermod -a -G dialout $USER

# Verify
mpremote --version
circup --version

# Check device appears when Pico is plugged in
ls -la /dev/ttyACM*
# Expected: crw-rw---- 1 root dialout ... /dev/ttyACM0
```

### Flashing CircuitPython Firmware (first time only)
1. Hold BOOTSEL on Pico while plugging in USB → mounts as `RPI-RP2`
2. Download latest CircuitPython UF2 for Raspberry Pi Pico from https://circuitpython.org/board/raspberry_pi_pico/
3. Copy UF2 to the RPI-RP2 drive — Pico reboots, mounts as `CIRCUITPY`
4. **Target CircuitPython 9.x** — 8.x has known ADC stability regressions on RP2040

---

## Core Libraries Needed

Install via `circup` once CircuitPython is on the device:

```bash
circup install adafruit_hid
circup install adafruit_debouncer
circup install adafruit_ssd1306        # if using OLED display
circup install adafruit_displayio_ssd1306  # alternative OLED driver
circup install adafruit_st7789         # if using TFT display
circup install adafruit_display_text
```

> **Library compatibility warning:** Adafruit display libraries have had breaking API changes across CircuitPython versions. If a display library fails to import or throws AttributeError, check the library version with `circup list` and try pinning to an older version. The `adafruit_ssd1306` vs `adafruit_displayio_ssd1306` split is a known source of confusion — which one works depends on your CircuitPython version.

---

## Development Workflow

### Single board — flash and monitor
```bash
# Copy code.py and open serial REPL immediately
mpremote connect /dev/ttyACM0 fs cp code.py :code.py + repl

# Copy a whole lib folder
mpremote connect /dev/ttyACM0 fs cp -r lib :lib

# Just monitor serial (Ctrl+] to exit)
mpremote connect /dev/ttyACM0 repl

# Soft reset without reflashing
# In REPL: Ctrl+D
```

### Two boards simultaneously
Second Pico appears as `/dev/ttyACM1`. Both can be monitored at once with a simple Python script:

```python
import serial, threading, datetime

def monitor(port, label):
    with serial.Serial(port, 115200, timeout=1) as s:
        while True:
            line = s.readline().decode('utf-8', errors='replace').strip()
            if line:
                ts = datetime.datetime.now().strftime('%H:%M:%S.%f')[:-3]
                print(f"[{ts}] {label}: {line}")

t0 = threading.Thread(target=monitor, args=('/dev/ttyACM0', 'BOARD-A'), daemon=True)
t1 = threading.Thread(target=monitor, args=('/dev/ttyACM1', 'BOARD-B'), daemon=True)
t0.start(); t1.start()
input("Monitoring both boards. Enter to stop.\n")
```

Save as `monitor_two.py` and run with `python3 monitor_two.py`.

### Iterating on bad/undocumented libraries
When a library behaves unexpectedly:
```bash
# Drop into live REPL and probe the object
mpremote connect /dev/ttyACM0 repl
# Then:
import adafruit_somethingbad
dir(adafruit_somethingbad)           # see what's actually exported
help(adafruit_somethingbad.Thing)    # docstring if present
```

---

## Starting Point: code.py

Minimal skeleton that initializes all hardware and prints sensor readings to serial. Start here and build up:

```python
import board
import analogio
import digitalio
import time

# --- Hardware Init ---

pressure_sensor = analogio.AnalogIn(board.GP26)

enc_a   = digitalio.DigitalInOut(board.GP18)
enc_b   = digitalio.DigitalInOut(board.GP19)
enc_btn = digitalio.DigitalInOut(board.GP20)
enc_a.direction   = digitalio.Direction.INPUT
enc_b.direction   = digitalio.Direction.INPUT
enc_btn.direction = digitalio.Direction.INPUT
enc_a.pull   = digitalio.Pull.UP
enc_b.pull   = digitalio.Pull.UP
enc_btn.pull = digitalio.Pull.UP

xac_puff = digitalio.DigitalInOut(board.GP16)
xac_sel  = digitalio.DigitalInOut(board.GP17)
xac_puff.direction = digitalio.Direction.OUTPUT
xac_sel.direction  = digitalio.Direction.OUTPUT
xac_puff.value = False
xac_sel.value  = False

# --- ADC Helpers ---

def raw_to_voltage(raw):
    """16-bit ADC raw → actual voltage at GP26 pin."""
    return (raw / 65535) * 3.3

def voltage_to_pressure_kpa(v):
    """
    Undo the voltage divider (10k/20k), recover sensor output,
    then apply MPX5010DP transfer function.
    Sensor Vout = v * (10k+20k)/20k = v * 1.5
    MPX5010DP: Vout = VS * (0.09 * P_kPa + 0.04), VS=5V
    Solving for P: P = (Vout/VS - 0.04) / 0.09
    """
    sensor_vout = v * 1.5        # undo divider
    p_kpa = (sensor_vout / 5.0 - 0.04) / 0.09
    return max(0.0, p_kpa)

# --- Main Loop ---

print("T-Rex Sip-N-Puff starting up")

while True:
    raw = pressure_sensor.value
    v   = raw_to_voltage(raw)
    kpa = voltage_to_pressure_kpa(v)

    print(f"raw={raw:5d}  v={v:.3f}V  p={kpa:.3f}kPa  "
          f"encA={enc_a.value} encB={enc_b.value} btn={not enc_btn.value}")

    time.sleep(0.1)
```

> **Calibration note:** The pressure-to-kPa formula assumes VS=5V (from VBUS). If you're powering the sensor from a regulated 5V rail that dips under load, the reading will drift. Add a 0.1µF decoupling cap on the sensor's VS pin if you see noise.

---

## Known Issues / Watch Points

- **ADC noise on RP2040:** The internal ADC has a known noise floor issue. Averaging 8–16 samples per reading significantly improves stability. The `analogio` library doesn't do this for you.
- **CircuitPython vs MicroPython:** These are different. Most Adafruit libraries target CircuitPython. MicroPython uses `machine.ADC`, not `analogio`. Don't mix them.
- **CIRCUITPY drive not mounting:** If the drive doesn't appear, the Pico may be in a crash loop. Hold BOOTSEL while plugging in to force bootloader mode, then re-flash CircuitPython UF2.
- **`mpremote` device permissions:** If `mpremote` returns "permission denied", your user isn't in `dialout` yet, or you haven't logged out/in since adding it. Quick workaround: `sudo mpremote ...` until you log back in.
- **Two boards same USB hub:** udev assigns ACM numbers by enumeration order. If both boards are plugged in at the same time the assignment can swap between reboots. Use udev rules keyed to USB serial number for stable naming in production.

---

## Files in This Repo

| Path | Description |
|---|---|
| `T-Rex_Sip_N_Puff.md` | Full project spec, use cases, BOM |
| `T-Rex_Sip_N_Puff_Hardware_Defitions.md` | Pin table and sub-circuit wiring detail |
| `T-Rex_Sip_N_Puff_Schematic.pdf` | Visual schematic (A3 landscape) for manual CAD entry |
| `T-Rex_Sip_N_Puff.kicad_sch` | KiCad 7 schematic (self-contained, all symbols embedded) |
| `photos/` | First article prototype build photos |
| `3d/` | STEP model of prototype assembly |
| `software_linux_notes.md` | This file |

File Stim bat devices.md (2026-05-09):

Stim bat devices

Modular button tops based on the soccer ball model

QR code reader

Variation / panel to put small rubber chicken sip n puff device vias its N pin connector

Make it so that Sip N Puff can be configured to commmunicate over i2c

Need big and fun rotary encoder covers

It is important to impliment the usd circuitpython compatiblity so the usd drive shows up as a drive when plugged in

test the mspm0 seesaw chip and combine with stripped fruit jam, get professional help and use AI to verify the design.  Consider reducing size of caps and resistors

Figure out what plastics we need and get with Prusa

pack an headphone cord for noise cancelling in travel bag

see if I have an mppm0 in my dev kits.  Set up pi to program mspm0 from fruit jam

computer://C%3A%5CUsers%5Clive%5CAppData%5CRoaming%5CClaude%5Clocal-agent-mode-sessions%5Cba3e0e48-28e1-49b9-a1f8-7ea908836150%5C7f503b71-e3d6-44c3-aeea-dab3fae66b33%5Clocal_a3eea2e6-fbd6-4b4c-bd55-3dd3ece0b414%5Coutputs%5C3dprintingnerd_collab_letter.docx

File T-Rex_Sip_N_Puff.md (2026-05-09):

# Project Documentation: The Sip-and-Puff "Rubber Chicken" Edition

## 1. Project Vision & Mission
The **Sip-and-Puff Rubber Chicken Edition** is a low-cost, open-source assistive technology bridge designed to convert breath pressure into digital control signals (rotary encoder and button inputs). It serves a dual-purpose role:
* **Primary Focus:** A robust, affordable sip-and-puff switch system for individuals with motor disabilities, such as spinal cord injuries, ALS, or cerebral palsy.
* **Secondary Focus:** An engaging "maker-grade" demonstration tool using rubber chickens as bellows to make assistive technology approachable for the general public at events like Maker Faires.

---

## 2. Core Operational Logic
The system emulates a rotary encoder with an integrated push-button using pressure sensor input.

### Input Mapping
| Action | Hardware Emulation | Behavior |
| :--- | :--- | :--- |
| **Single Puff** | Rotary Increment (+1) | Mimics one "click" of a rotary encoder. |
| **Puff and Hold** | Continuous Scroll | Increments repeatedly; higher pressure results in a faster increment rate. |
| **Double Puff** | Button Press / Select | Interpreted as the "click" of the encoder shaft to select an item. |
| **Sip (Optional)** | Negative Increment (-1) | Decrements values (supported by differential sensors like the MPX5010DP). |

---

## 3. Maker Faire Engagement: The "Chicken Challenge" Game
To showcase the technology, a dedicated game station will be featured at the booth.

### Hardware Setup
* **T-Rex Talker Station:** A standalone AAC unit with a 320x240 color screen.
* **Interface:** The T-Rex Sip-and-Puff is plugged directly into the station.
* **Display Layout:** The lower 320x200 section of the screen displays 8 selectable communication categories.

### Gameplay Mechanics
* **The Start:** A player squeezes the rubber chicken once to initiate a run.
* **The Quiz:** 10 questions appear sequentially. Players must map "real-world" feelings to the correct AAC category (e.g., if the screen asks "I drank too much soda?", the player must select the "I need to use the bathroom" section).
* **Feedback:** The device speaks the selected phrase aloud after every choice before proceeding to the next question.
* **Scoring:** * The total score is the time taken to complete all 10 questions.
    * **Penalty:** A 30-second penalty is added for each incorrect selection.
    * **Timer Logic:** The timer pauses while the device is speaking to ensure users are not penalized for the system's vocal processing time.
* **Leaderboard:** The station tracks the "Best Time" between rounds, with prizes awarded for the lowest overall time.
* **Educational Context:** A large poster behind the station with graphics will explain the mechanics and the importance of accessible interfaces.

---

## 4. Hardware & Power Specifications

### Microcontroller & Sensors
* **Microcontroller:** Raspberry Pi Pico / RP2040, chosen for cost-effectiveness and dual-core processing.
* **Pressure Sensor:** MPX5010DP Differential Pressure Sensor (0-100 kPa range).

### Power & Battery Life (500 mAh Basis)
* **Default Operation:** ~50mA draw (Pico + Sensor + LEDs), providing roughly 10 hours of continuous use.
* **Low-Power Architecture:** For portable versions, the system can transition to an **RP2350** or **TI MSPM0**.
* **Deep Sleep Logic:** The sensor can be powered down during idleness. To wake the device, a user must perform a prolonged sip or puff (exceeding the configurable sleep timer), allowing the sensor time to reach reading stability.

### Safety & Processor Selection
* **Standard Version:** Raspberry Pi RP2040 for maker environments.
* **Medical/Safety Version:** For applications seeking **FDA safety certification**, the design requires:
    * **Redundancy:** Dual processors cross-verifying signals.
    * **Certified Hardware:** A safety-qualified processor such as the **TI Hercules (TMS570)** or the **STM32 Silicon Functional Safety** line.

---

## 5. Integration Use Cases

### Use Case 1: T-Rex Talker Integration
* **1a: I2C Polling:** Host device polls the Pico for state changes.
* **1b: Encoder Input:** Plugs directly into the T-Rex Talker’s rotary encoder port.
* **1c: I2C with Data Ready:** Uses the **'Button/Int' line** as a hardware interrupt to signal the software when data is ready for retrieval.

### Use Case 2: Xbox Adaptive Controller (XAC)
* Connects via 3.5mm mono jacks using **optocouplers (PC817)** to mimic "dry contact" switches.

---

## 6. Goals and Research Objectives

1.  **Global Accessibility:** Create an affordable sip-and-puff switch for worldwide use, targeting a **$25-$50** price point.
2.  **Open Source Philosophy:** Provide full documentation and code to the community.
3.  **HCI Research:** Serve as a platform for studying accessible interface design and user experience.
4.  **Academic Publication:** Establish a foundation for research papers in IEEE accessibility venues.
5.  **Engineering Education:** Provide a hands-on STEM project for learning about sensors and assistive design.

---
*Created for Maker Faire 2026 Demonstration.*

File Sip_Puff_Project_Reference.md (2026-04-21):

# Sip-and-Puff / Mouth-Operated Input: Open-Source Project Reference

*A living reference covering four open-source assistive input projects — what each solved, what remains unsolved, the technical methods chosen, and springboard insights for forward development.*

**Compiled:** April 2026

---

## Contents

1. [Purpose of This Document](#1-purpose-of-this-document)
2. [Quick Comparison Matrix](#2-quick-comparison-matrix)
3. [Project 1 — openSipPuff (jasonwebb)](#3-project-1--opensippuff-jasonwebb)
4. [Project 2 — The 'Sup / SipNPuff_Mouse (Bobcatmodder)](#4-project-2--the-sup--sipnpuff_mouse-bobcatmodder)
5. [Project 3 — FLipMouse (asterics)](#5-project-3--flipmouse-asterics)
6. [Project 4 — LipSync (Makers Making Change)](#6-project-4--lipsync-makers-making-change)
7. [Cross-Project Patterns and Lessons](#7-cross-project-patterns-and-lessons)
   - [7.6 Configuration Requires a Computer or a Developer — Always](#76-configuration-requires-a-computer-or-a-developer--always)
   - [7.7 ESD / Circuit Protection Is Almost Universally Absent](#77-esd--circuit-protection-is-almost-universally-absent)
8. [Springboard: Gaps to Exploit in Your Project](#8-springboard-gaps-to-exploit-in-your-project)
9. [Reference Links](#9-reference-links)
10. [Lessons Learned and To Be Implemented](#10-lessons-learned-and-to-be-implemented)
    - [10.1 Breath Hygiene Filtering](#101-breath-hygiene-filtering)
    - [10.2 Wireless Connectivity — Bluetooth Implementation](#102-wireless-connectivity--bluetooth-implementation)
    - [10.3 Joystick / Cursor Movement — IMU-Based Head Tracking](#103-joystick--cursor-movement--imu-based-head-tracking)
    - [10.4 Pressure Sensor Selection — LPS28DFWTR as Default](#104-pressure-sensor-selection--lps28dfwtr-as-default)
    - [10.5 Optional Display Hardware — Built-in PCB Support](#105-optional-display-hardware--built-in-pcb-support)
    - [10.6 Circuit Protection — SP724AHTG on External I/O Lines](#106-circuit-protection--sp724ahtg-on-external-io-lines)
    - [10.7 Medical Certification Pathway — Redundant Sensor and Safety CPU](#107-medical-certification-pathway--redundant-sensor-and-safety-cpu)

---

## 1. Purpose of This Document

This document serves as a permanent, self-contained reference that eliminates the need to re-read the original GitHub repositories and Instructables pages. It distills the design decisions, technical approaches, solved problems, and known limitations from four significant open-source sip-and-puff / mouth-operated assistive input projects. The goal is to give you and a future AI session an immediate, actionable picture of the landscape so your project can leap forward from the best of what already exists.

Each project is summarised under consistent headings so direct comparison is easy. Section 7 synthesises cross-cutting patterns, and Section 8 maps the gaps your project can fill.

---

## 2. Quick Comparison Matrix

| Feature | openSipPuff (jasonwebb) | The 'Sup (Bobcatmodder) | FLipMouse (asterics) | LipSync (MMC) | Gap / Your Potential |
|---|---|---|---|---|---|
| **MCU** | ATmega32u4 | Arduino Pro Micro | Arduino Nano RP2040 | Arduino platform | Your choice |
| **Position sensing** | None (breath only) | Analog joystick | Strain gauges (4×DMS) | Hall-effect 3D magnet | **Post-Maker-Faire: BNO055 9-DOF IMU — Mode A: head strap/glasses mount; Mode B: straw collar tongue joystick. Same hardware, config-file switch. Hall-effect stick as further stretch goal.** |
| **Pressure sensor** | MPXV7007GP (analog) | MPXV7002DP | Dedicated sensor | LPS33HW + LPS22 (I²C) | **✓ LPS28DFWTR (I²C, water-resistant, 24-bit) — default; MPX5010DP through-hole alternative** |
| **USB HID** | ✓ kbd/mouse/MIDI | ✓ mouse | ✓ mouse/kbd/gamepad | ✓ mouse/gamepad | ✓ (table stakes) |
| **Bluetooth** | ✗ | ✗ | ✓ (RP2040 + ESP32) | ✓ (module, retired) | ✓ — critical gap |
| **Joystick + sip unified** | ✗ | ✓ (3D-printed) | ✓ (mouthpiece) | ✓ (Joystick unit) | ✓ |
| **Separate sip/puff threshold** | ✗ | ✗ | ✓ | ✓ | ✓ must-have |
| **Config slots** | ✗ | ✗ | ✓ (EEPROM) | ✓ (Hub display) | ✓ with display |
| **Text file config** | ✗ | ✗ | ✗ (WebGUI only) | ✗ (Hub only) | **✓ — primary differentiator: USB mass storage config file, no reflashing, no PC app required** |
| **Display / UI** | ✗ | ✗ | Web GUI (PC only) | Hub OLED | **✓ J1: 1" 128×64 I²C OLED (SSD1306) + J2: 2–4" SPI color LCD (ST7789/ILI9341) — PCB connectors built in** |
| **External switches** | ✗ | ✗ | 2× 3.5 mm jack | 3× 3.5 mm jack | 3+ jacks |
| **IR env. control** | ✗ | ✗ | ✓ (record+replay) | ✗ | Nice-to-have |
| **Hygiene filter** | ✗ | ✗ (noted risk) | ✓ | ✓ | ✓ required |
| **OSHWA certified** | ✗ | ✗ | ✗ | ✓ CA000046 | Consider |
| **Approx. build cost** | $60–100 target | < $50 | ~$100–150 est. | $175–325 | Target < $150 |
| **Project status** | Stalled ~2014 | Active (2017+) | Actively maintained | Actively maintained | — |

---

## 3. Project 1 — openSipPuff (jasonwebb)

**GitHub:** https://github.com/jasonwebb/openSipPuff

### 3.1 Overview

openSipPuff is a minimalist, standalone sip-and-puff USB interface designed around the philosophy of keeping part count and assembly steps to an absolute minimum while maximising creative expressiveness. Created by Jason Webb around 2013, it targets breath-based control of keypresses, mouse actions, MIDI, and any other USB HID function — all without requiring special drivers on the host computer.

### 3.2 Hardware

- **MCU:** ATmega32u4 running the Arduino Leonardo bootloader. Native USB HID — no LUFA, no additional USB chip.
- **Pressure sensor:** MPXV7007GP (NXP/Freescale). Analog output, ±7 kPa range, normalised to 0.5 V–4.5 V. Rests at ~2.5 V; positive pressure drives voltage up, negative (sip) drives it down.
- **I²C expansion port:** 4-pin header (VCC, GND, SDA, SCL) exposes the processed analog data stream — lets other boards tap into breath data.
- **Form factor:** Custom PCB (OSH Park, Rev B). No onboard joystick or directional sensor.

### 3.3 What It Solved

- **Driverless USB HID:** The ATmega32u4 appears as a standard mouse/keyboard/MIDI device on any OS immediately.
- **Low part count:** Reduced BOM to MCU + single pressure sensor + passives. Very replicable.
- **Analog breath resolution:** Unlike binary switch-based designs, the MPXV7007GP provides a continuous 0–1023 analog value, enabling variable-speed scrolling, velocity-sensitive MIDI notes, or proportional mouse speed.
- **Expansion via I²C:** Other microcontrollers or modules can read the breath data directly without duplicating the sensor circuit.
- **Target cost:** Designed to stay under $60–$100 retail, far below commercial equivalents.
- **MIDI as first-class output:** Explicitly planned as a creative tool, not just a clinical AT device.

### 3.4 What It Did NOT Solve / Known Limitations

- **No directional / cursor movement:** openSipPuff is breath-only. There is no joystick, trackball, or gyroscope — the device cannot move a cursor by itself.
- **Binary sip vs. puff only in practice:** Although analog values are available, the reference firmware exposed only threshold-based events, not continuous values, to the USB HID layer.
- **No Bluetooth:** USB-only. Cannot drive a smartphone or tablet wirelessly.
- **No configuration UI:** No display, no on-device settings. Changes require firmware re-flashing.
- **No hygiene filter:** No provision for saliva capture or breath filtration.
- **Project stalled ~2014:** After Rev B prototype boards were built and tested, the project lost momentum due to "a few small problems" and never shipped commercially or reached end users systematically. Last commit activity circa 2013–2014.
- **No external switch inputs:** No 3.5 mm jack provisions for external assistive switches.

### 3.5 Technical Method & Springboard Value

The key insight here is the MPXV7007GP pressure sensor paired with an ATmega32u4. The sensor's ±7 kPa range covers the full human breath force range, and the analog output wires directly to an ADC pin — the simplest possible sip/puff circuit. The I²C tap-out idea is ahead of its time: it allows a modular architecture where a separate board handles position tracking while openSipPuff handles breath.

**For your project:** Adopt this sensor pattern (or the water-resistant LPS33HW as an upgrade), keep the ATmega32u4 or RP2040 for USB HID, and add the missing pieces (joystick, display, BT) on top.

> **Note:** The MPXV7007GP has been superseded. Consider NXP MPXV7007DP (dual-port) or Adafruit LPS33HW for a water-resistant I²C alternative.

---

## 4. Project 2 — The 'Sup / SipNPuff_Mouse (Bobcatmodder)

**GitHub:** https://github.com/Bobcatmodder/SipNPuff_Mouse  
**Instructables:** https://www.instructables.com/The-Sup-a-Mouse-for-Quadriplegics-Low-Cost-and-Ope/
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

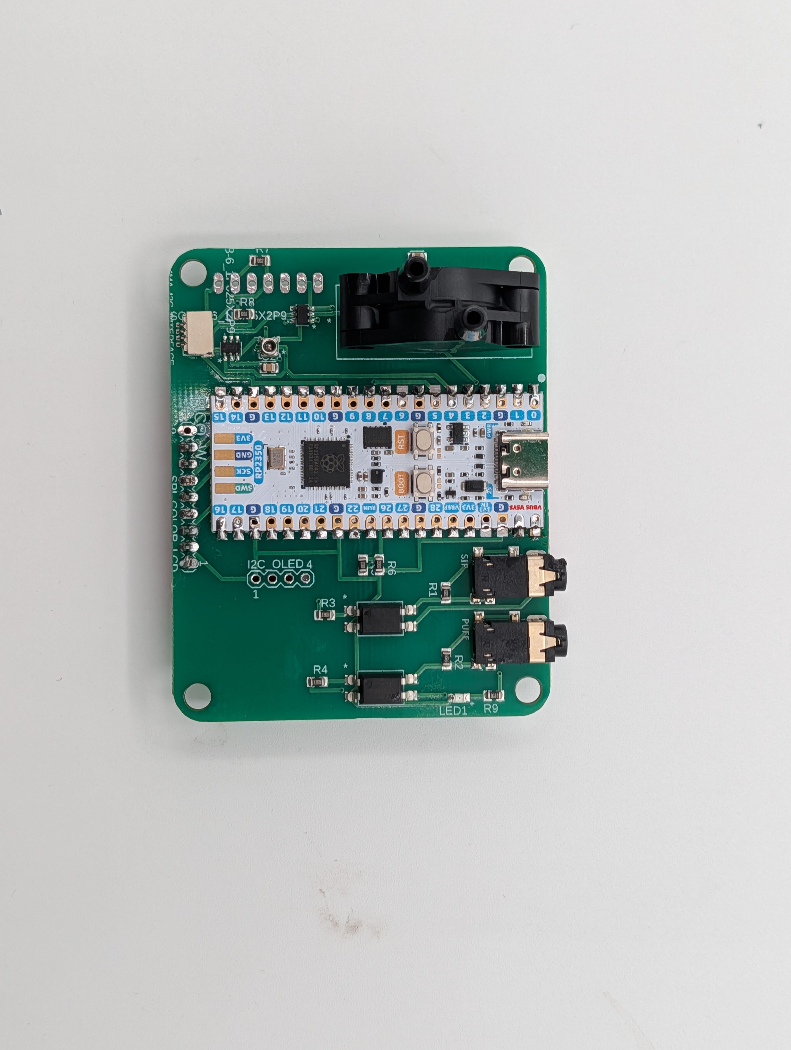
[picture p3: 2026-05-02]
photos/PXL_20260430_184725425.MP.jpg

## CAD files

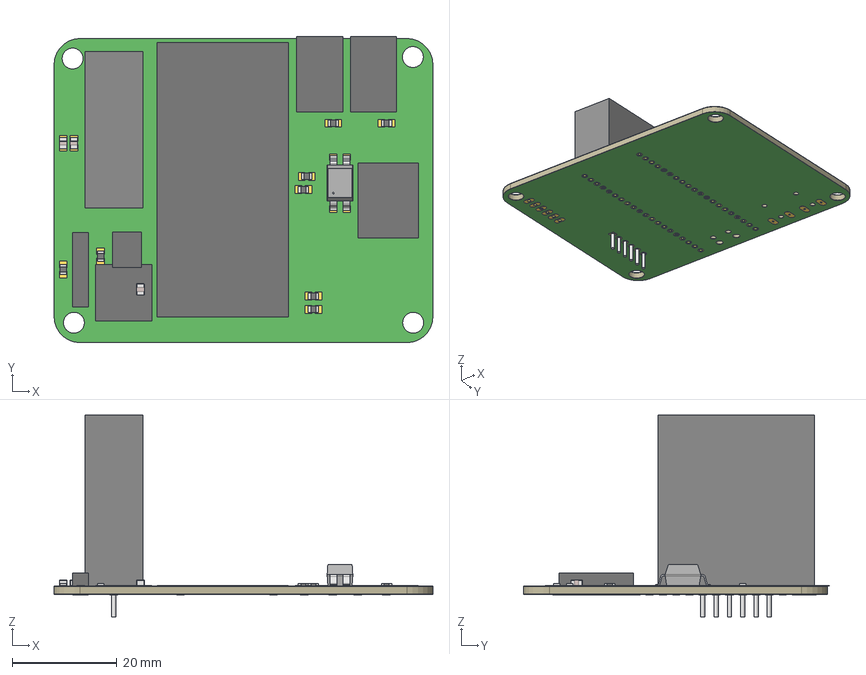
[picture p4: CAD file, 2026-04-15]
SipNPuff.step
72.4 x 58.5 x 38.5 mm
Board
1-copper
64-copper
1-soldermask
64-soldermask
SL-4_DOD
SL-4_DOD v1
MPX5010DP_MOT v1
MA06-1
PICO-PKG-NO_DEBUG
Ferrite x 8
Contact x 16
JST_SH4
PJ-332A x 2
9216945.f3d x 3
CCLGA7_LPS28DFWTR_STM

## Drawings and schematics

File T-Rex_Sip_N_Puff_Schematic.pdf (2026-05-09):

# T-REX SIP-N-PUFF HID — SCHEMATIC

## Raspberry Pi Pico | MPX5010DP | XAC Optocoupled Outputs | Encoder + I2C Interface

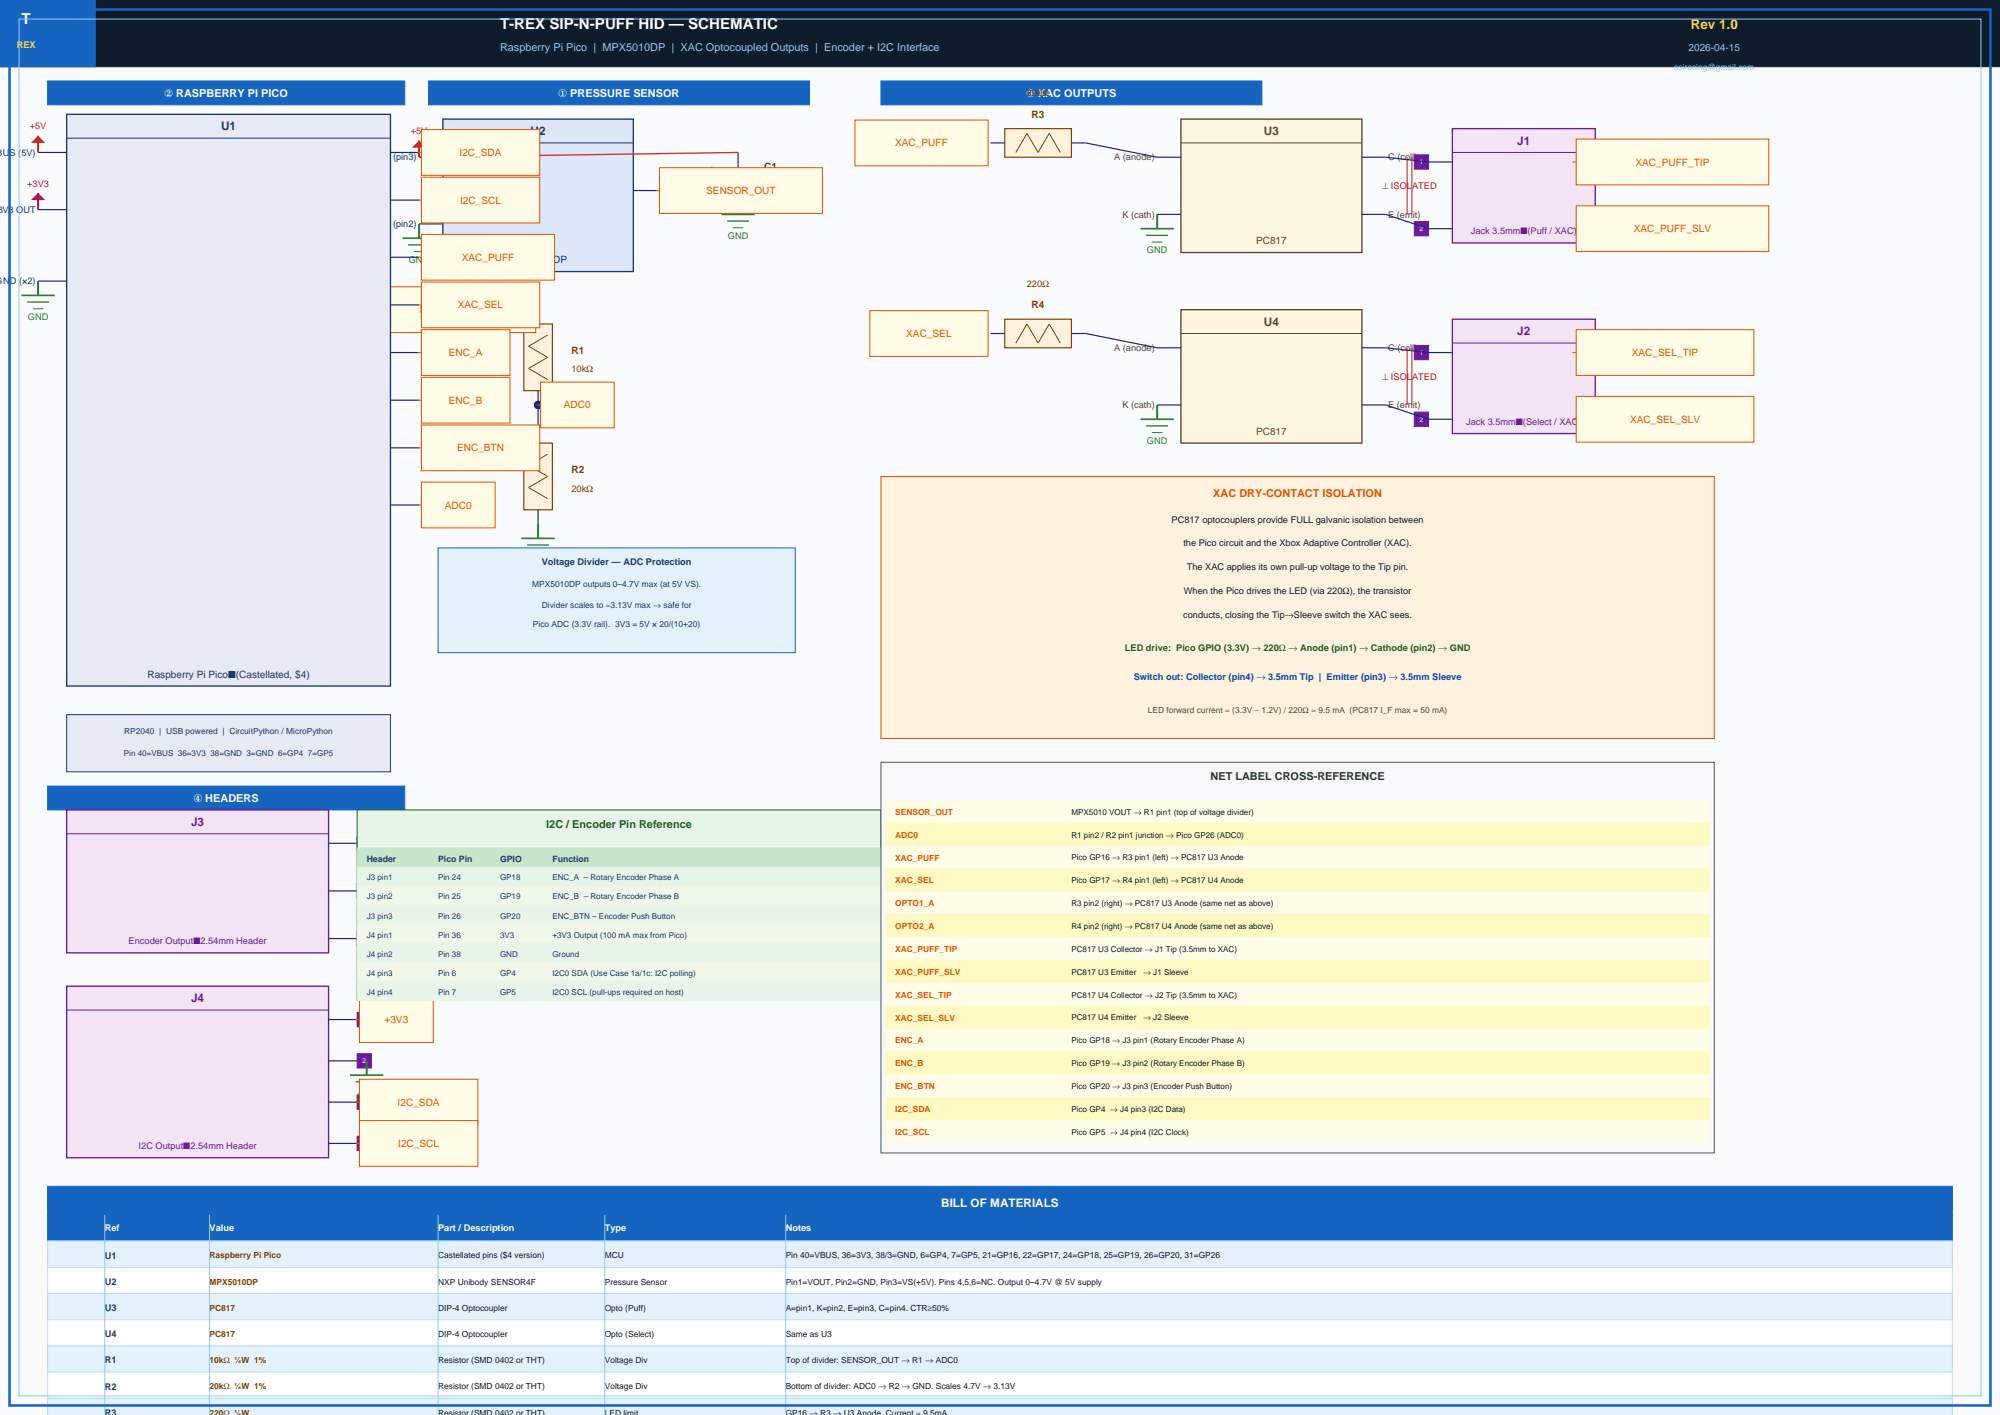
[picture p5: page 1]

XAC DRY-CONTACT ISOLATION

PC817 optocouplers provide FULL galvanic isolation between

the Pico circuit and the Xbox Adaptive Controller (XAC).

GNDVoltage Divider — ADC Protection

The XAC applies its own pull-up voltage to the Tip pin.

MPX5010DP outputs 0–4.7V max (at 5V VS).

When the Pico drives the LED (via 220Ω), the transistor

Divider scales to ≈3.13V max → safe for

conducts, closing the Tip→Sleeve switch the XAC sees.

LED drive: Pico GPIO (3.3V) → 220Ω → Anode (pin1) → Cathode (pin2) → GND

Raspberry Pi Pico■(Castellated, $4)

Switch out: Collector (pin4) → 3.5mm Tip | Emitter (pin3) → 3.5mm Sleeve

LED forward current ≈ (3.3V − 1.2V) / 220Ω ≈ 9.5 mA (PC817 I_F max = 50 mA)

RP2040 | USB powered | CircuitPython / MicroPython

Pin 40=VBUS 36=3V3 38=GND 3=GND 6=GP4 7=GP5

NET LABEL CROSS-REFERENCE

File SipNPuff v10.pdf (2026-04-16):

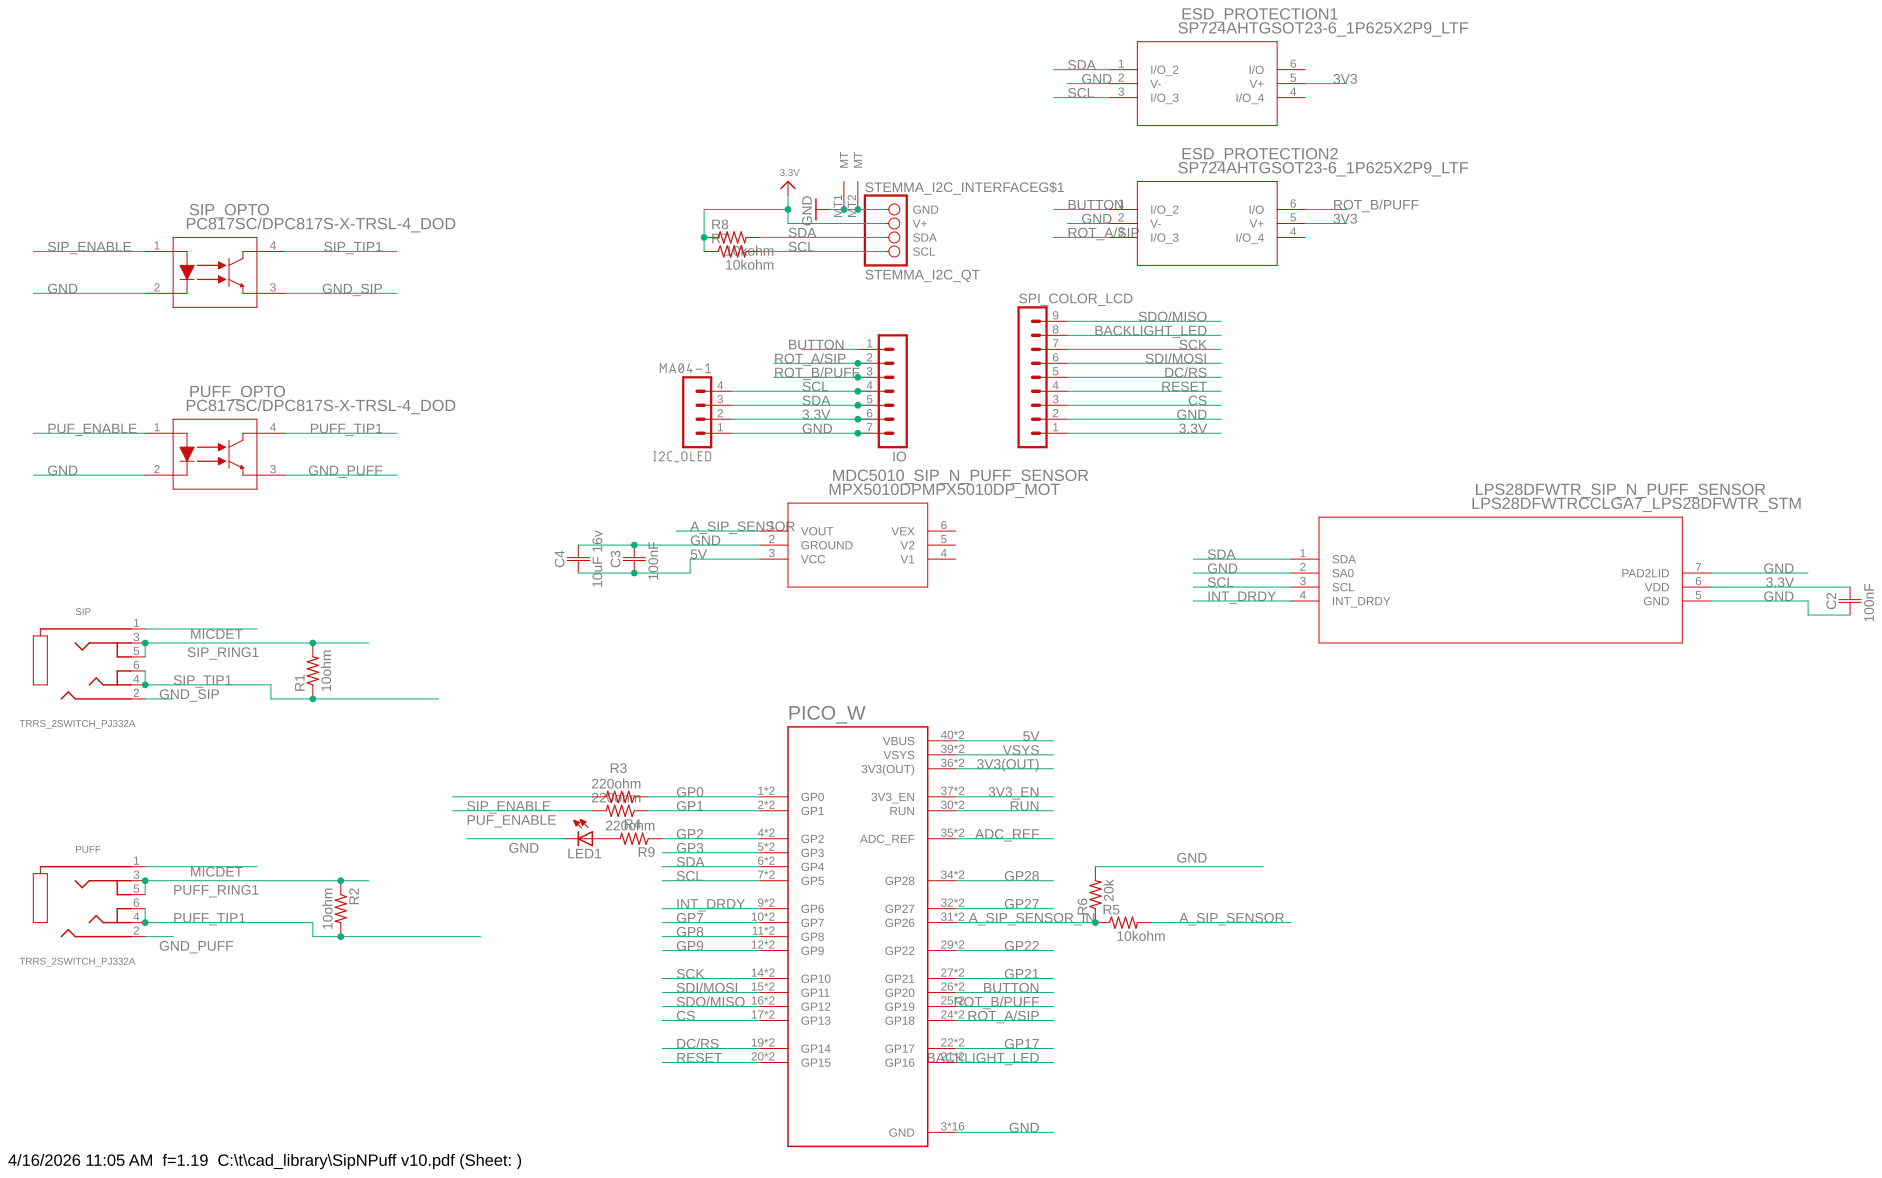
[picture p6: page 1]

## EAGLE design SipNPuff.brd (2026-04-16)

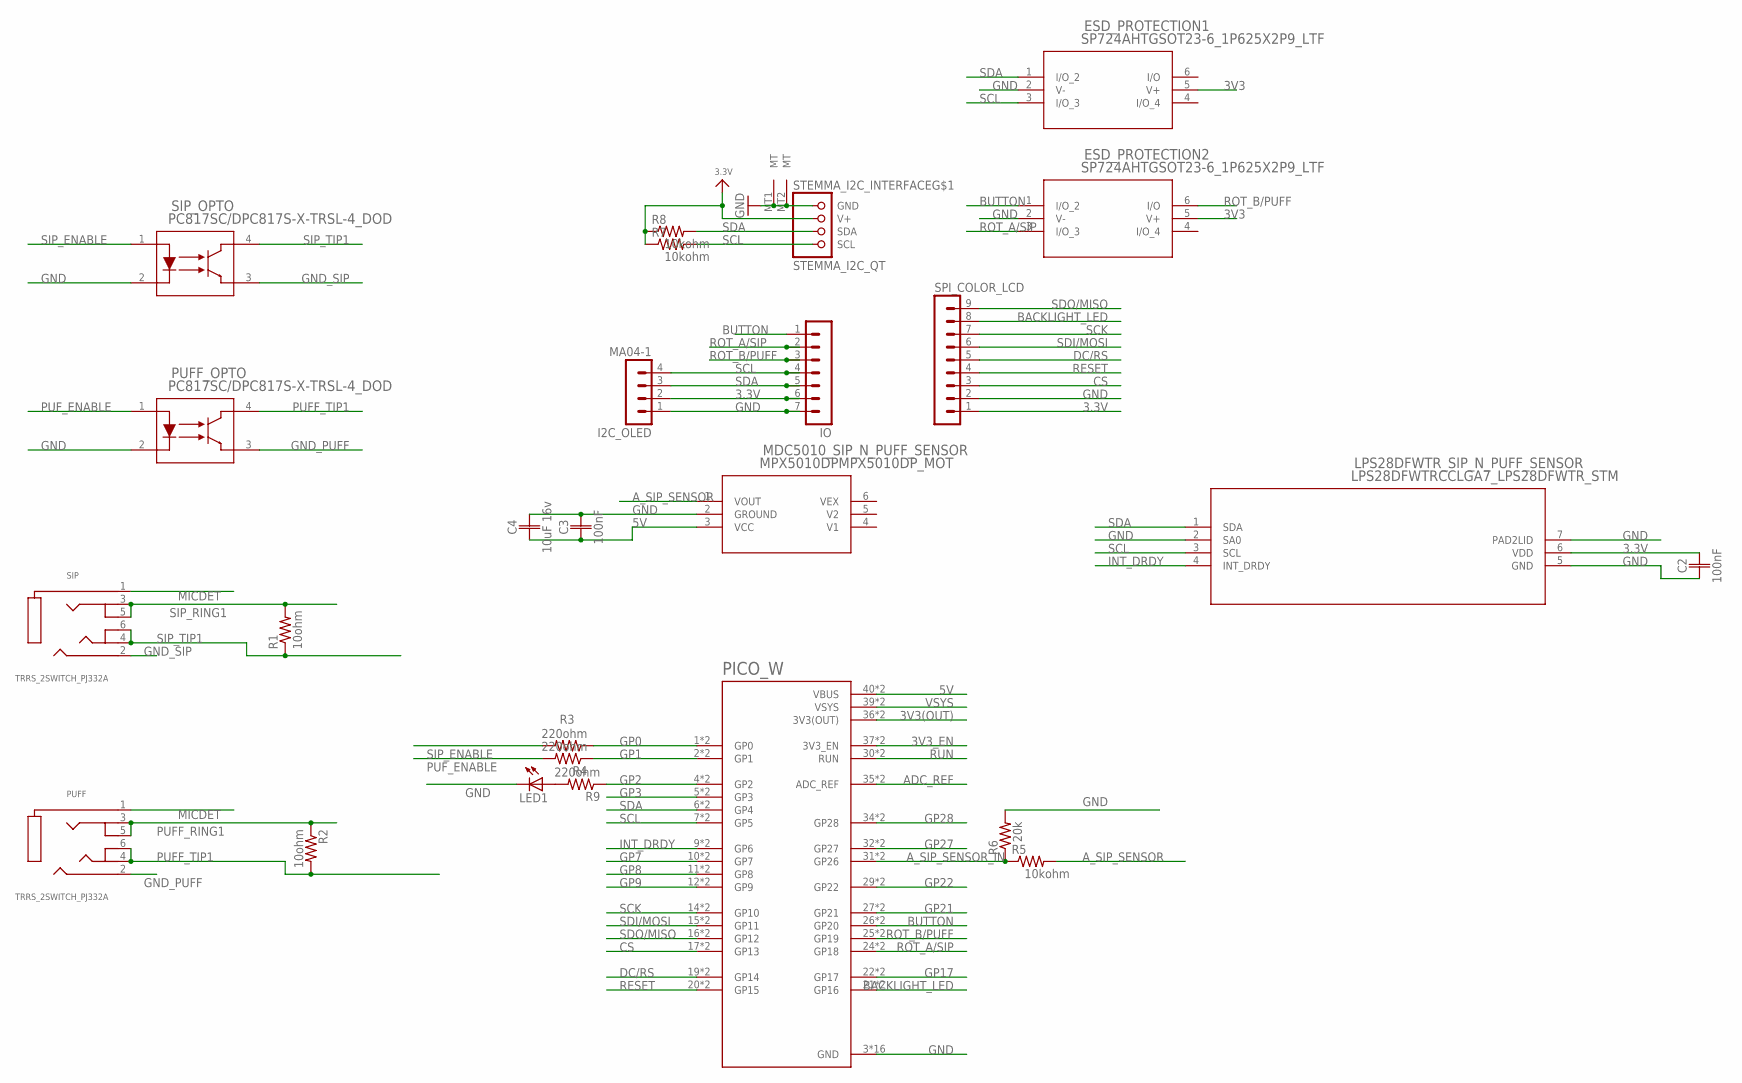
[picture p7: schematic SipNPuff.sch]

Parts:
C2, C3: 100nF; CAPC2012X110
C4: 10uF 16v; CAPC2012X110
ESD_PROTECTION1, ESD_PROTECTION2: SP724AHTGSOT23-6_1P625X2P9_LTF; SOT23-6_1P625X2P9_LTF
I2C_OLED: MA04-1
IO: MA07-1
LED1: LEDCHIP-LED0805; CHIP-LED0805
LPS28DFWTR_SIP_N_PUFF_SENSOR: LPS28DFWTRCCLGA7_LPS28DFWTR_STM; CCLGA7_LPS28DFWTR_STM
MDC5010_SIP_N_PUFF_SENSOR: MPX5010DPMPX5010DP_MOT; MPX5010DP_MOT
PICO_W: RASPBERRY_PICO-NO_DEBUG; PICO-PKG-NO_DEBUG
PUFF: TRRS_2SWITCH_PJ332A; PJ-332A
PUFF_OPTO: PC817SC/DPC817S-X-TRSL-4_DOD; SL-4_DOD
R1, R2: 10ohm; R0805
R3, R4, R9: 220ohm; R0805
R5, R7, R8: 10kohm; R0805
R6: 20k; R0805
SIP: TRRS_2SWITCH_PJ332A; PJ-332A
SIP_OPTO: PC817SC/DPC817S-X-TRSL-4_DOD; SL-4_DOD
SPI_COLOR_LCD: MA09-1
STEMMA_I2C_INTERFACE: STEMMA_I2C_QT; JST_SH4

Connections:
3.3V: C2.2, I2C_OLED.2 (B), IO.6, LPS28DFWTR_SIP_N_PUFF_SENSOR.6 (VDD), R7.1, R8.1, SPI_COLOR_LCD.1, STEMMA_I2C_INTERFACE.2 (V+)
3V3(OUT): PICO_W.36 (3V3(OUT)), PICO_W.P$36 (3V3(OUT))
3V3_EN: PICO_W.37 (3V3_EN), PICO_W.P$37 (3V3_EN)
5V: C3.1, C4.1, MDC5010_SIP_N_PUFF_SENSOR.3 (VCC), PICO_W.40 (VBUS), PICO_W.P$40 (VBUS)
ADC_REF: PICO_W.35 (ADC_REF), PICO_W.P$35 (ADC_REF)
A_SIP_SENSOR: MDC5010_SIP_N_PUFF_SENSOR.1 (VOUT), R5.2
A_SIP_SENSOR_IN: PICO_W.31 (GP26), PICO_W.P$31 (GP26), R5.1, R6.1
BACKLIGHT_LED: PICO_W.21 (GP16), PICO_W.P$21 (GP16), SPI_COLOR_LCD.8
BUTTON: ESD_PROTECTION2.1 (I/O_2), IO.1, PICO_W.26 (GP20), PICO_W.P$26 (GP20); also elsewhere on the board
CS: PICO_W.17 (GP13), PICO_W.P$17 (GP13), SPI_COLOR_LCD.3
DC/RS: PICO_W.19 (GP14), PICO_W.P$19 (GP14), SPI_COLOR_LCD.5
GND: C2.1, C3.2, C4.2, ESD_PROTECTION1.2 (V-), ESD_PROTECTION2.2 (V-), I2C_OLED.1 (A), IO.7, LED1.C, LPS28DFWTR_SIP_N_PUFF_SENSOR.2 (SA0), LPS28DFWTR_SIP_N_PUFF_SENSOR.5 (GND), LPS28DFWTR_SIP_N_PUFF_SENSOR.7 (PAD2LID), MDC5010_SIP_N_PUFF_SENSOR.2 (GROUND), PICO_W.3 (GND), PICO_W.8 (GND), PICO_W.13 (GND), PICO_W.18 (GND), PICO_W.23 (GND), PICO_W.28 (GND), PICO_W.33 (GND), PICO_W.38 (GND), PICO_W.P$3 (GND), PICO_W.P$8 (GND), PICO_W.P$13 (GND), PICO_W.P$18 (GND), PICO_W.P$23 (GND), PICO_W.P$28 (GND), PICO_W.P$33 (GND), PICO_W.P$38 (GND), PUFF_OPTO.2 (CATHODE), R6.2, SIP_OPTO.2 (CATHODE), SPI_COLOR_LCD.2, STEMMA_I2C_INTERFACE.1 (GND), STEMMA_I2C_INTERFACE.MT1 (MT), STEMMA_I2C_INTERFACE.MT2 (MT); also elsewhere on the board
GND_PUFF: PUFF.2 (RING1), PUFF_OPTO.3 (EMITTER)
GND_SIP: SIP.2 (RING1), SIP_OPTO.3 (EMITTER)
GP0: PICO_W.1 (GP0), PICO_W.P$1 (GP0), R3.1
GP1: PICO_W.2 (GP1), PICO_W.P$2 (GP1), R4.1
GP2: PICO_W.4 (GP2), PICO_W.P$4 (GP2), R9.1
GP3: PICO_W.5 (GP3), PICO_W.P$5 (GP3)
GP7: PICO_W.10 (GP7), PICO_W.P$10 (GP7)
GP8: PICO_W.11 (GP8), PICO_W.P$11 (GP8)
GP9: PICO_W.12 (GP9), PICO_W.P$12 (GP9)
GP17: PICO_W.22 (GP17), PICO_W.P$22 (GP17)
GP21: PICO_W.27 (GP21), PICO_W.P$27 (GP21)
GP22: PICO_W.29 (GP22), PICO_W.P$29 (GP22)
GP27: PICO_W.32 (GP27), PICO_W.P$32 (GP27)
GP28: PICO_W.34 (GP28), PICO_W.P$34 (GP28)
INT_DRDY: LPS28DFWTR_SIP_N_PUFF_SENSOR.4 (INT_DRDY), PICO_W.9 (GP6), PICO_W.P$9 (GP6)
MICDET: PUFF.1 (RING), SIP.1 (RING)
unnamed: LED1.A, R9.2
unnamed: ESD_PROTECTION1.5 (V+), ESD_PROTECTION2.5 (V+)
PUFF_RING1: PUFF.3 (RING2), PUFF.5 (R2_SW), R2.1
PUFF_TIP1: PUFF.4 (TIP), PUFF.6 (TIP_SW), PUFF_OPTO.4 (COLLECTOR), R2.2
PUF_ENABLE: PUFF_OPTO.1 (ANODE), R4.2
RESET: PICO_W.20 (GP15), PICO_W.P$20 (GP15), SPI_COLOR_LCD.4
ROT_A/SIP: ESD_PROTECTION2.3 (I/O_3), IO.2, PICO_W.24 (GP18), PICO_W.P$24 (GP18); also elsewhere on the board
ROT_B/PUFF: ESD_PROTECTION2.6 (I/O), IO.3, PICO_W.25 (GP19), PICO_W.P$25 (GP19); also elsewhere on the board
RUN: PICO_W.30 (RUN), PICO_W.P$30 (RUN)
SCK: PICO_W.14 (GP10), PICO_W.P$14 (GP10), SPI_COLOR_LCD.7
SCL: ESD_PROTECTION1.3 (I/O_3), I2C_OLED.4 (D), IO.4, LPS28DFWTR_SIP_N_PUFF_SENSOR.3 (SCL), PICO_W.7 (GP5), PICO_W.P$7 (GP5), R7.2, STEMMA_I2C_INTERFACE.4 (SCL); also elsewhere on the board
SDA: ESD_PROTECTION1.1 (I/O_2), I2C_OLED.3 (C), IO.5, LPS28DFWTR_SIP_N_PUFF_SENSOR.1 (SDA), PICO_W.6 (GP4), PICO_W.P$6 (GP4), R8.2, STEMMA_I2C_INTERFACE.3 (SDA); also elsewhere on the board
SDI/MOSI: PICO_W.15 (GP11), PICO_W.P$15 (GP11), SPI_COLOR_LCD.6
SDO/MISO: PICO_W.16 (GP12), PICO_W.P$16 (GP12), SPI_COLOR_LCD.9
SIP_ENABLE: R3.2, SIP_OPTO.1 (ANODE)
SIP_RING1: R1.2, SIP.3 (RING2), SIP.5 (R2_SW)
SIP_TIP1: R1.1, SIP.4 (TIP), SIP.6 (TIP_SW), SIP_OPTO.4 (COLLECTOR)
VSYS: PICO_W.39 (VSYS), PICO_W.P$39 (VSYS)

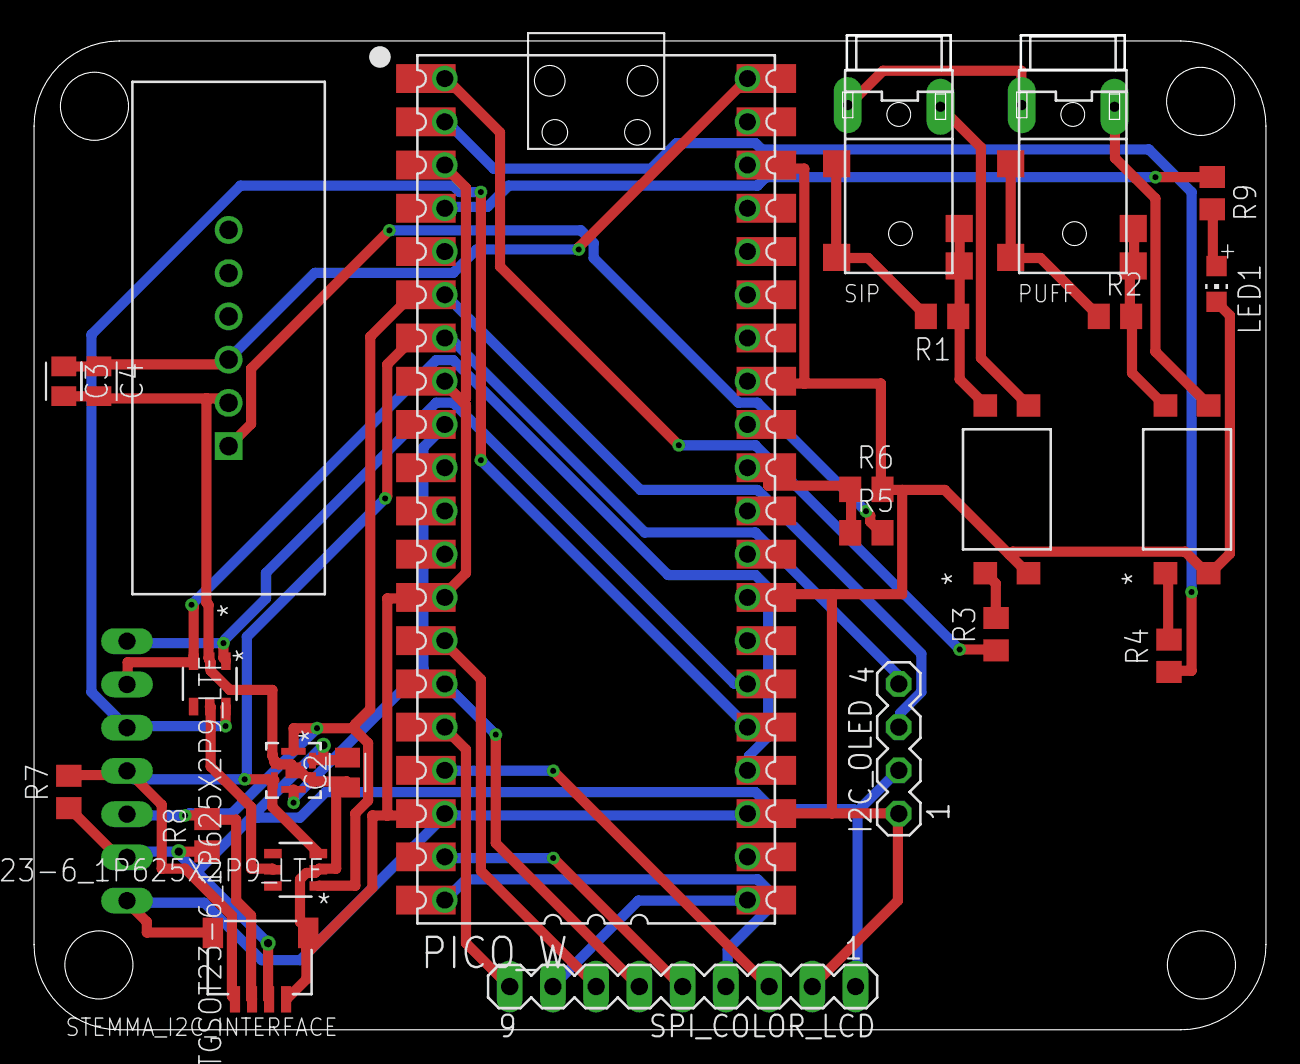
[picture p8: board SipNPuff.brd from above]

Board: 2 copper layers, 72.4 x 58.1 mm, 26 parts (1 on the bottom side), 46 nets.

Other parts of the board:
U1, U2: SP724AHTGSOT23-6_1P625X2P9_LTF; SOT23-6_1P625X2P9_LTF

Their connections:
3V3: U1.5, U2.5
BUTTON: U1.1; also elsewhere on the board
GND: U1.2, U2.2; also elsewhere on the board
ROT_A/SIP: U1.3; also elsewhere on the board
ROT_B/PUFF: U1.6; also elsewhere on the board
SCL: U2.3; also elsewhere on the board
SDA: U2.1; also elsewhere on the board

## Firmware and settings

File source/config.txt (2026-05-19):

# T-Rex Sip-N-Puff user configuration.
#
# This file lives at the root of the CIRCUITPY drive. Edit it with
# any text editor and unplug/replug the Pico to reload. Anything
# not listed here keeps the default from hardware_config.py.
#
# Format: key = value. Lines starting with # are comments.

# =====================================================================
# RUN MODE
# =====================================================================
# run         : normal operation — drives encoder/mouse + XAC outputs
# diagnostic  : streams sensor data to serial, NO outputs driven.
mode    = run
verbose = true

# =====================================================================
# OUTPUT MODE
# =====================================================================
# encoder : wired rotary-encoder + buttons. Drives:
#             - GP18 / GP19 = quadrature A/B (CW = puff, CCW = sip)
#             - GP20        = encoder pushbutton (short puff)
#             - GP21        = button 2 (short sip)
#             - GP0 / GP1   = XAC opto pulses, fired in sync with
#                             every CW/CCW rotation tick as well as
#                             the short puff/sip button presses.
#           Use this to feed the T-Rex Talker's encoder port and any
#           other device that reads quadrature + button closures.
#           NOTE: at default repeat_max_hz = 20 and xac_pulse_s = 0.05
#           the XAC pulses run back-to-back during a sustained breath.
#           Lower xac_pulse_s or repeat_max_hz if your XAC consumer
#           needs a visible gap.
#
# mouse   : USB HID mouse driven by the BNO08x IMU. Drives:
#             - Cursor x/y from the rate-based pointing stream
#             - Short puff = LEFT mouse click
#             - Short sip  = RIGHT mouse click
#             - Held puff  = scroll wheel UP
#             - Held sip   = scroll wheel DOWN
#             - Double puff = MIDDLE click (reserved)
#           Requires CircuitPython's default HID composite (mouse +
#           keyboard + consumer-control) — no boot.py changes needed.
#
# Event semantics in BOTH modes:
#   short = breath ends within hold_to_repeat_s (default 0.4s)
#   held  = breath sustained past hold_to_repeat_s (emits *_repeat)
#   double = two breaths within double_*_window_s
output_mode = encoder

# Mouse-mode tunables.
# Per-tick motion below this is dropped (no HID report sent). Lets
# the gyro deadband sit a hair above zero without flooding the host.
mouse_motion_min_per_tick = 1
# Scroll-wheel amount per puff_repeat / sip_repeat tick.
mouse_scroll_per_repeat = 1

# Heartbeat: how often the live status line is printed to USB-CDC.
# Dropped to 2.0 s while bringing up the LPS28 plumbing so the
# peak(puf, sip) field updates quickly while testing breath strength.
# Raise back to 5-10 s for production once thresholds are dialed in.
heartbeat_period_s = 2.0

# =====================================================================
# DISPLAY
# =====================================================================
# Pick the panel you have, or "none". Whitespace, case and underscores
# are all interchangeable, so all three of these mean the same thing:
#
#     display = SSD1306 OLED 128x64
#     display = ssd1306_oled_128x64
#     display = ssd1306-oled-128x64
#
# Supported values:
#
#   none                                   ← no display attached
#
#   ssd1306 oled 128x64                    ← I2C OLED on J1 (most common)
#   ssd1306 oled 128x32                    ← skinnier 128x32 I2C OLED
#
#   st7735r color lcd 128x160 greentab     ← 1.8" SPI TFT, GreenTab
#   st7735r color lcd 128x160 redtab       ← 1.8" SPI TFT, RedTab
#   st7735r color lcd 128x160 blacktab     ← 1.8" SPI TFT, BlackTab
#   st7735r color lcd 128x128              ← 1.44" square
#   st7735r color lcd 80x160               ← 0.96" wide
#
#   st7789 color lcd 240x240               ← 1.3"/1.5" IPS square
#   st7789 color lcd 240x320               ← 2.0"/2.4" IPS portrait
#   st7789 color lcd 135x240               ← 1.14" Pico-Display style
#
#   ili9341 color lcd 240x320              ← 2.2"-3.2" 240x320 panels
#   gc9a01 color lcd 240x240 round         ← 1.28" round
display = none

# Throttle redraws regardless of which panel is selected.
display_update_hz = 10
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

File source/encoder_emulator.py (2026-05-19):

"""Quadrature encoder emulation on three GPIOs.

Drives ENC_A, ENC_B, ENC_BTN as outputs to look like a mechanical
rotary encoder with a pushbutton. Used to plug the Sip-N-Puff
directly into the T-Rex Talker's existing rotary encoder port.

Quadrature pattern for one CW click (A leads B):

    A: 1 0 0 1 1
    B: 1 1 0 0 1

CCW is the same pattern with A and B swapped. Each phase is held
for ``encoder_phase_s`` so a host polling at sub-kHz can capture
the transitions reliably.

Idle level is HIGH on all three lines, matching a typical encoder
with an internal pull-up at the host side.
"""

import time
import digitalio

from hardware_config import _pin


# Quadrature gray code — full sequence for one CW click. The first
# entry is the idle state which we restore between clicks so a host
# state machine that keys off level (rather than edge) is happy.
_CW_SEQ  = ((1, 1), (0, 1), (0, 0), (1, 0), (1, 1))
_CCW_SEQ = ((1, 1), (1, 0), (0, 0), (0, 1), (1, 1))


class _OpenDrainOutput:
    """Open-drain output that survives any CircuitPython port.

    ``digitalio.DriveMode.OPEN_DRAIN`` is supposed to do this, but in
    practice the RP2040/RP2350 CP build has been observed leaving the
    pin in a high-Z-ish state when value=False is set — so the "low"
    half of the cycle never actually pulls to 0 V. To sidestep that,
    we manage open-drain ourselves by flipping ``direction``:

      * ``value = True``  → ``direction = INPUT``. If ``pull_up`` is
        True the pin enables the internal pull-up (~50 kΩ to 3.3 V) so
        the line floats up like a real switch's pull-up; otherwise pull
        is None and a host-side pull-up must supply the high level.
      * ``value = False`` → ``direction = OUTPUT`` and the line is
        driven actively to 0 V.

    Exposes the same ``.value`` getter/setter shape as
    ``digitalio.DigitalInOut`` so callers stay unchanged.
    """

    def __init__(self, pin, initial=True, pull_up=False):
        self._io = digitalio.DigitalInOut(pin)
        self._pull_up = bool(pull_up)
        self._value = None
        self.value = initial

    @property
    def value(self):
        return self._value

    @value.setter
    def value(self, v):
        v = bool(v)
        if v:
            self._io.direction = digitalio.Direction.INPUT
            self._io.pull = (digitalio.Pull.UP if self._pull_up else None)
        else:
            # Drive low. Disable the pull *first* (while we're still
            # in INPUT mode so the pull setter accepts the write) so
            # the internal pull-up isn't sourcing into our active
            # sink — guarantees the line reaches 0 V cleanly.
            if self._io.direction == digitalio.Direction.INPUT:
                self._io.pull = None
            self._io.direction = digitalio.Direction.OUTPUT
            self._io.value = False
        self._value = v

    def deinit(self):
        self._io.deinit()


def _make_push_pull(pin, initial=True):
    """Plain push-pull output: drives 0 V low and 3.3 V high."""
    io = digitalio.DigitalInOut(pin)
    io.direction = digitalio.Direction.OUTPUT
    io.value = initial
    return io


def _make_output(pin, initial=True, drive_mode="push_pull"):
    """Configure ``pin`` according to the requested drive mode.

    ``drive_mode`` is one of:
      * ``"push_pull"`` (default) — actively drives 3.3 V high and
        0 V low. Stiff output; works against any host but fights
        any host pull-up the line might already have.
      * ``"simulated_pullup"`` — high state is the Pico's internal
        pull-up (~50 kΩ to 3.3 V), low state actively sinks to 0 V.
        Emulates a real mechanical encoder/switch: line idles high
        via a soft pull-up, snaps low only while pressed.
      * ``"open_drain"`` — like ``simulated_pullup`` but **without**
        the internal pull-up; the high state is fully high-Z and a
        host-side pull-up must supply the high level. Safer interop
        with 5 V hosts than ``simulated_pullup``.
    """
    mode = (drive_mode or "push_pull").strip().lower()
    if mode == "simulated_pullup":
        return _OpenDrainOutput(pin, initial=initial, pull_up=True)
    if mode == "open_drain":
        return _OpenDrainOutput(pin, initial=initial, pull_up=False)
    return _make_push_pull(pin, initial=initial)


class EncoderEmulator:
    """Drive A/B/BTN as a quadrature encoder + pushbutton.

    Args:
        config: variant config dict (encoder_*_pin and timing keys).
    """

    def __init__(self, config):
        self._phase_s        = float(config["encoder_phase_s"])
        self._btn_active_low = bool(config["encoder_button_active_low"])
        self._btn_press_s    = float(config["encoder_button_press_s"])
        self._verbose        = bool(config.get("verbose", False))
        # Drive mode applies to all encoder output lines (A, B, BTN,
        # BTN2). See _make_output() for the trade-offs.
        self._drive_mode     = str(config.get(
            "encoder_drive_mode", "push_pull")).strip().lower()
        # Click protocol on A/B — see click_cw / click_ccw.
        #   "pulse_encoder"   = momentary pulse on a single line per
        #                       click (A for CW, B for CCW). XAC-style.
        #   "5_phase_encoder" = full gray-code quadrature sequence.
        self._protocol = str(config.get(
            "encoder_protocol", "pulse_encoder")).strip().lower()
        # When true, press2() (short-sip) drives the encoder shaft
        # button (BTN, GP20) instead of BTN2 (GP21). Hosts with only
        # one "select" input wire short-puff and short-sip together.
        self._fold_btn2_onto_btn = bool(config.get(
            "map_both_clicks_to_encoder_button", False))

        self._a    = None
        self._b    = None
        self._btn  = None
        self._btn2 = None
        self._available = False

        try:
            self._a   = _make_output(_pin(config["enc_a_pin"]),
                                     initial=True,
                                     drive_mode=self._drive_mode)
            self._b   = _make_output(_pin(config["enc_b_pin"]),
                                     initial=True,
                                     drive_mode=self._drive_mode)
            self._btn = _make_output(
                _pin(config["enc_btn_pin"]),
                initial=self._btn_idle_level(),
                drive_mode=self._drive_mode,
            )
            self._available = True
            print("Encoder: A={} B={} BTN={} "
                  "(phase={:.4f}s, drive={}, protocol={})".format(
                      config["enc_a_pin"], config["enc_b_pin"],
                      config["enc_btn_pin"], self._phase_s,
                      self._drive_mode, self._protocol))
        except Exception as e:
            print("Encoder: init failed ({})".format(e))
            return
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

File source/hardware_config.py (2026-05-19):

"""Hardware configuration for the T-Rex Sip-N-Puff device.

Pin map, sensor coefficients, and tunable thresholds are kept here.
Run-time-tunable values (thresholds, timings, mode) are overlaid by
config.txt at startup via _load_user_config().

Pin names are stored as strings (e.g. "GP26") and resolved at init
time with _pin() so the same config dict can be sanity-printed
without touching hardware.
"""

import board


def _pin(name):
    """Resolve a pin name string (e.g. "GP26") to a board pin object.

    Returns None when name is None so optional pins can be omitted
    from the config without special-casing each call site.
    """
    if name is None:
        return None
    return getattr(board, name)


# --- Variant definitions -----------------------------------------

# pico2_mpx5010dp:
#   Raspberry Pi Pico 2 (RP2350) with MPX5010DP analog pressure sensor.
#   This is the through-hole "Maker Faire" build variant.
VARIANTS = {
    "pico2_mpx5010dp": {
        # --- Sensor: MPX5010DP analog, voltage-divider'd to ADC ---
        "pressure_pin": "GP26",
        "pressure_supply_v": 5.0,        # MPX5010DP nominal VS
        "pressure_divider_ratio": 1.5,   # (10k+20k)/20k — undo at ADC
        # MPX5010DP transfer fn: Vout = VS * (0.09 * P_kPa + 0.04)
        "mpx_offset": 0.04,
        "mpx_slope": 0.09,
        # ADC oversampling — RP2040/RP2350 ADCs have a noise floor
        # so averaging is mandatory for stable thresholding.
        "pressure_oversample": 16,

        # --- Encoder emulation outputs ---
        "enc_a_pin":   "GP18",
        "enc_b_pin":   "GP19",
        "enc_btn_pin": "GP20",
        # Second momentary-button output: short sip in encoder mode.
        # Wired as a sibling of enc_btn — tie host-side as another
        # button-to-GND switch with its own pull-up.
        "enc_btn2_pin": "GP21",
        # Quadrature half-period: time spent in each of the 4 phases
        # of one click. 2 ms gives a 4 ms click — well below typical
        # mechanical encoder rates and easy for any host to capture.
        "encoder_phase_s": 0.002,
        # Active-low button: idle = high, pressed = low (matches a
        # typical encoder shaft switch with internal pull-up on host).
        "encoder_button_active_low": True,
        "encoder_button_press_s": 0.05,

        # --- Xbox Adaptive Controller dry-contact outputs ---
        # Two independent PC817 optocouplers — one per breath direction.
        # Each Pico GPIO drives the opto's anode through a 220 Ω resistor.
        "xac_puff_pin": "GP1",   # Puff_enable -> 220R -> PC817 anode
        "xac_sip_pin":  "GP0",   # Sip_enable  -> 220R -> PC817 anode
        # PC817 forward-biased = signal asserted to XAC.
        # Pico GPIO HIGH lights the LED → XAC sees switch closed.
        "xac_active_low": False,
        "xac_pulse_s": 0.05,
        # Gap between the two pulses of a double-tap. Must be long
        # enough that the host registers two distinct closures.
        "xac_double_gap_s": 0.05,

        # --- Breath thresholds (kPa above baseline) ---
        # Tuned for an unloaded MPX5010DP and a rubber-chicken bellows.
        # Override these in config.txt after benchtop calibration.
        "puff_on_kpa":  0.30,
        "puff_off_kpa": 0.20,   # hysteresis: must drop below this to release
        "sip_on_kpa":  -0.30,
        "sip_off_kpa": -0.20,

        # --- Event timings ---
        # Two puffs whose release-to-press gap is below this window
        # are treated as a "double puff" (== select).
        "double_puff_window_s": 0.45,
        # Symmetric for sip — kept independent so puff and sip can
        # be tuned to a user's asymmetric breath profile.
        "double_sip_window_s": 0.45,
        # Hold-to-scroll: after this much continuous puff, start
        # emitting repeat ticks at a pressure-scaled rate.
        "hold_to_repeat_s": 0.40,
        "repeat_min_hz":  3.0,    # tick rate at puff_on_kpa
        "repeat_max_hz": 20.0,    # tick rate at repeat_full_scale_kpa
        "repeat_full_scale_kpa": 3.0,

        # --- Optional 1.8" SPI color LCD (ST7735R, 128x160) ---
        # Wiring matches J2 connector in project reference doc 10.5.
        # XAC optos now live on GP0 / GP1 (see above), so the LCD
        # backlight on GP16 has no pin conflict to worry about.
        "display_enabled":     True,
        "display_controller":  "st7735r",
        "display_width":       128,
        "display_height":      160,
        "display_rotation":    270,         # landscape, USB at the right
        # 4 MHz is the safe-bet first-light value for cheap modules
        # on unshielded leads. Once the panel is proven, raise to
        # 12–24 MHz from config.txt.
        "display_baudrate":    4_000_000,
        "display_sck_pin":     "GP10",
        "display_mosi_pin":    "GP11",
        "display_miso_pin":    "GP12",      # not used by ST7735, but claimed by busio.SPI
        "display_cs_pin":      "GP13",
        "display_dc_pin":      "GP14",
        "display_reset_pin":   "GP15",
        "display_backlight_pin": "GP16",    # set to None if tied to 3.3V
        # I2C bus for OLED variants (J1 connector — Section 10.5 of
        # the project reference doc). Shared with pressure sensor and
        # any future IMU.
        "display_i2c_sda_pin": "GP4",
        "display_i2c_scl_pin": "GP5",
        "display_i2c_address": 0x3C,        # 0x3C default, 0x3D alternative
        # 100 kHz is the safe-bet first-light value. Many cheap
        # SSD1306 modules ETIMEDOUT during init at 400 kHz on
        # unshielded jumper wires; once you've confirmed the panel
        # works, raise to 400 kHz for a snappier refresh.
        "display_i2c_frequency": 100_000,
        "display_update_hz":   10,          # throttle redraws
        # Tab-type offsets. Aliexpress 1.8" panels are most often
        # the "GreenTab" variant: visible pixels start at column 2,
        # row 1 within the controller's framebuffer. If the screen
        # stays blank or shows garbage at the edge, try:
        #   RedTab:    colstart=0, rowstart=0, bgr=False
        #   BlackTab:  colstart=0, rowstart=0, bgr=True
        #   M5Stack:   colstart=0, rowstart=0, invert=True
        "display_colstart":  2,
        "display_rowstart":  1,
        "display_bgr":       False,
        "display_invert":    False,
        # Boot-time R/G/B/W flash so a wiring or driver problem is
        # visible immediately. Set false once you trust the display.
        "display_test_pattern": True,
        "display_bg_color":    0x000000,
        "display_text_color":  0xFFFFFF,
        "display_puff_color":  0xFF6020,    # warm orange
        "display_sip_color":   0x2080FF,    # cool blue
        "display_threshold_color": 0x808080,
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

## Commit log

2026-04-15 Initial commit of project
    Should be a rapid development for what I think will be a quick first working release
    [SipNPuff.f3d, SipNPuff.step]
2026-04-15 Updates to include additional sensor
    [SipNPuff.f3d, SipNPuff.step]
2026-04-16 Additional updates from research and inspiration and move from .f3d to .sch and .brd format on electronics files for better sharing
    [SipNPuff.brd, SipNPuff.sch]
2026-04-16 Updates based on additional research and inspiration. Moved from .f3d format for electronics to .sch and .brd from Eagle Cad as it is more standard
    [SipNPuff.f3d]
2026-04-16 Added PDF of schematice for more widespread review. It is quick and dirty, but everything is meaningfully labeled
2026-04-17 Added a use case where IMU is mounted directly to straw
2026-05-02 Add readme.md for prototype photo documentation
    Added prototype photos of the T-Rex Sip-N-Puff HID electronics assembly
2026-05-02 Incomplete 3d model
    Of first prototype not all electronic components have good models, but the Sensors are fully rendered and all the holes and connectors are in place for making plastic from
2026-05-02 Photos of 1st Article
    Photos from first article with both sip-n-puff sensor installed and showing 2 different optional displays OLED and Color LCD
2026-05-09 Add CircuitPython firmware and supporting documentation
    source/ contains the working sip-and-puff firmware for an RP2350
    (Pico 2) target: pressure sensing (MPX5010DP analog + LPS28DFW I2C),
    breath classifier with hysteresis and double-puff/sip windows,
    encoder + XAC dry-contact outputs, and a 4-bargraph status display
    that runs on either a 1.8" ST7735R LCD or a 128x64 SSD1306 OLED via
    the same DisplayManager. config.txt holds runtime-tunable thresholds
    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
    [config.txt]
2026-05-19 Firmware bring-up: LPS28 fusion, IMU pointing, event-indicator HUD
    Major changes from the May 2026 bench sessions, in roughly the order
    the work landed:
    Pressure pipeline
    - Switch classifier input to LPS28 (bidirectional) for both branches;
    MPX5010DP is unidirectional (0-10 kPa, can't measure sip).
    - Per-direction signal scaling (puff_signal_scale, sip_signal_scale)
    to compensate for asymmetric breath effort; defaults 2.0/1.0 for
    the current plumbing.
    - LPS28 baseline auto-rezero after a long stable-idle window,
    catching slow thermal/leak drift between boot and now.
    Classifier
    - Per-direction puff/sip hold-to-repeat threshold so taps don't
    accidentally trigger scrolls.
    - Repeat-s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
    [config.txt]
2026-05-19 Encoder: pulse-protocol default, drive-mode options, BTN2 fold
    Three new encoder configuration options for host interop:
    encoder_protocol
    - pulse_encoder (default) -- each CW/CCW click pulses A or B
    low for encoder_button_press_s, same shape as BTN/BTN2 press.
    What the Xbox Adaptive Controller and similar dry-contact
    hosts want: each wire is an independent momentary switch.
    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
    [config.txt]

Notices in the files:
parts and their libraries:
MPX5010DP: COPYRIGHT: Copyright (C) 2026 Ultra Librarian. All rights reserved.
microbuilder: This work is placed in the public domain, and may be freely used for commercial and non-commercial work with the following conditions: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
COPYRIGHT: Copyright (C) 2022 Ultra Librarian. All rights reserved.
